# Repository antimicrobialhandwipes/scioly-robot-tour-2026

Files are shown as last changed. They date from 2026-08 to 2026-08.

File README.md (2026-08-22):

# Scioly Robot Tour 2025-2026
An autonomous robot developed for BTHS Science Olympiad during the **2025–2026** season.

The system combines odometry, distance-sensing, and careful calibration to navigate a competition course and interact with objects under strict time and dimensional constraints.
#

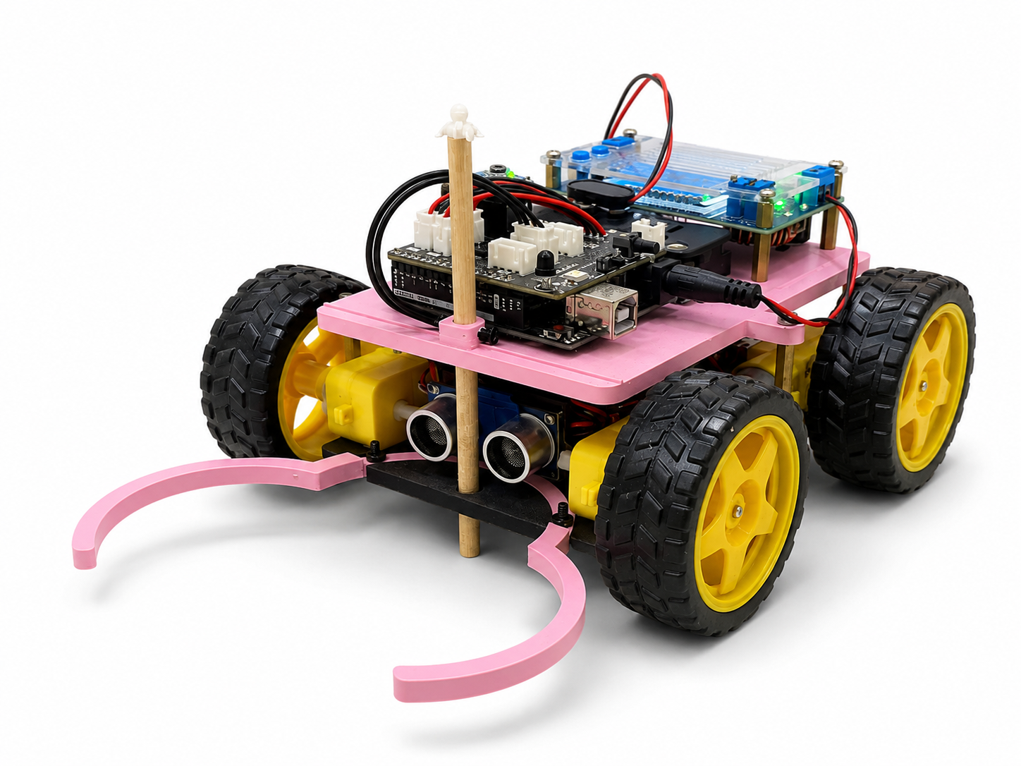
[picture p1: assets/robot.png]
Robot Tour robot


## Overview
<u>Robot Tour</u> requires an autonomous vehicle to navigate a predefined course, interact with objects, and complete a sequence of movements accurately within a specified amount of time.

I developed and iterated on the robot's mechanical and software systems throughout the 2024–2025 and 2025–2026 seasons. The 2025–2026 implementation significantly expanded on its original distance-measuring system by **adding a magnetic encoder that directly measured how far the wheels rotated**. Instead of brute-forcing distance based mainly on time, the robot could use the physical circumference of its wheels to calculate how far it had traveled.

- **MT6701 magnetic encoder** — measures wheel rotation for distance estimation
- **MPU6050 IMU** — provides yaw measurements for heading correction
- **Ultrasonic sensor** — measures distance to objects and course features
- **RGB LED** — provides real-time motion and calibration feedback

## Results

### 2025-2026
[**Science Olympiad at the University of Pennsylvania (SOUPS)**](https://www.duosmium.org/results/2026-02-14_penn_invitational_c/): 3rd Place<br>
[**Princeton University Science Olympiad**](https://www.duosmium.org/results/2026-02-07_princeton_invitational_c/): 5th Place<br>
[**New York City South Regional Tournament**](https://www.duosmium.org/results/2026-01-31_NY_nyc_south_regional_c/): 5th Place<br>
[**Rickards Science Olympiad Invitational**](https://www.duosmium.org/results/2025-11-01_rickards_invitational_c/): 9th Place<br>

### 2024-2025
[**New York Science Olympiad State Tournament**](https://www.duosmium.org/results/2025-03-21_NY_states_c/): 1st Place<br>
[**New York City South Regional Tournament**](https://www.duosmium.org/results/2025-02-01_NY_new_york_city_south_regional_c/): 1st Place<br>
[**Columbia University Science Olympiad**](https://www.duosmium.org/results/2025-01-25_columbia_university_invitational_c/): 2nd Place<br>
[**Boyceville Satellite Science Olympiad Invitational**](https://www.duosmium.org/results/2024-12-02_boyceville_satellite_invitational_c/): 3rd Place<br>
[**Rickards Science Olympiad Invitational**](https://www.duosmium.org/results/2024-11-02_rickards_invitational_c/): 5th Place<br>

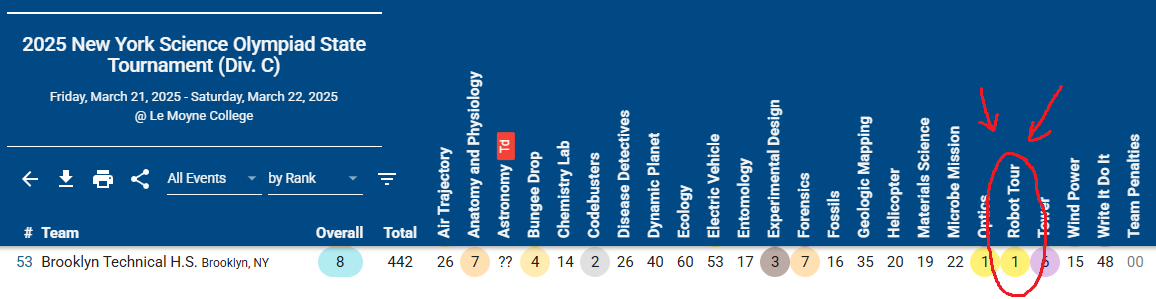
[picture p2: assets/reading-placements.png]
Reading Placements


## Motion Control
### Encoder-Based Movement
The **2024-2025** version mainly used carefully calibrated timing to control how long the motors ran to reach a certain distance. (which later caused issues with friction and voltage)

For **2025–2026**, I transitioned to an encoder-based measurement approach.

## Heading Control
The MPU6050 provides a continuous yaw feedback during movement to keep the robot straight (a basic proportional controller)

The controller compares the measured yaw against a target heading:

- **yaw error = target heading − measured heading**

If the robot begins to stray from its target heading, the motor speeds adjust asymmetrically to correct the trajectory. 

The same feedback loop is also used during turns. The robot progressively reduces its turning speed as it approaches a target heading, allowing it to settle within approximately a one-degree tolerance during calibration.

## Calibration
Because the robot is affected by real-world physical factors, I'm considering factors, such as robot dimensions, wheel diameter, motor characteristics, battery voltage, surface friction, alignment, and sensor offsets. So therefore I calibrated movement systems around the physical robot.

This repository includes a `Robot Tour Data Sheet` documenting measured movements and the corresponding movement commands that we commonly need for competitions.

The calibration data covers:
* Forward movement
* Distance-based approaches
* Distance-based corrections
* 90° turns
* 180° turns
* Positioning relative to course objects

The goal was not simply to make the robot complete one track, but to develop reusable movement primitives that could be calibrated and integrated into different tracks.

## Movement Glossary
| Function: | Purpose: |
| :---- | ----- |
| fw(d) | Move forward **d** centimeters |
| bw(d) | Move backward **d** centimeters |
| r() | Rotate 90° right |
| l() | Rotate 90° left |
| r180() | Rotate 180° right |
| l180() | Rotate 180° left |
| fu(d) | Move forward until **d** centimeters from an object |
| until(d) | Move backwards until **d** centimeters from an object |

## Example Track

The `Example Track/` directory contains a complete track that won us 3rd at the SOUPS (Science Olympiad at the University of Pennsylvania).

For example:

fu(21.5);<br>
l();<br>
fw(50);<br>
fw(50);<br>
r();<br>
fw(50);<br>
l();<br>
fw(50);<br>
l180();<br>
fw(50);<br>

The corresponding `directions.txt` file provides a human-readable representation of the route before it is inputted into the Arduino program. This separation makes it easier to design and revise routes.

## Development History
### 2024–2025

The original version relied heavily on empirically calibrated timing constants.

For example, forward and backward movement were determined using relationships between:

- movement distance
- motor speed
- elapsed time
- braking behavior

This approach was functional but sensitive to changes in battery voltage, motor behavior, and physical conditions.

### 2025–2026

The movement system was redesigned around measured wheel rotation.

Major improvements included:

- Added MT6701 magnetic encoder
- Replaced primary distance estimation with encoder-based odometry
- Added acceleration/deceleration profiles
- Improved heading correction
- Added dedicated 180° turning routines
- Refined ultrasonic distance-based positioning
- Reorganized movement into reusable high-level primitives
- Added documented physical calibration data

## Hardware

Constructed utilizing parts from a [ELEGOO Robot Car Kit](https://www.amazon.com/dp/B07KPZ8RSZ?lv=shuf&channelId=500&plpRedirect=mhFallback) (Arduino UNO, Kit Shield, MPU6050 IMU, Yellow DC gearbox motors), two custom CAD-designed baseplates and claw grips, dowel with a cadded ducky for good luck, ultrasonic sensors, 8-pack battery holder (w/ non-rechargeable alkaline batteries as per construction parameters), magnetic encoders (MT6701), and [DC Buck Converter](https://a.co/d/06xhJ2Bz),

Designed on Bambu Studio and printed on Bambu Lab A1 Mini

Constructed following the 2025-2026 SciOly build parameters: [Link](https://drive.google.com/file/d/1CcOrLIdCGCBEwNyRmbU7zTlQBbmRYcFV/view)

## Credits
The 2024–2025 implementation was based in part on a kit design and includes code credited to Jason Wei. (CWRU' 29)

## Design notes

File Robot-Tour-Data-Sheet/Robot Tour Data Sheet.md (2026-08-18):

**Robot Tour Movement Data Sheet:**

Disclaimers: 

\* These are all manual calibrations based off the robot’s physical conditions (length and width)  
\* forward(), backward(), forwardUntil(), until() are all measurements based off the dowel  
\* Movement functions have integer arguments, so decimals get truncated

| Situation: | Before: | After: | Code: |
| :---- | :---- | :---- | ----- |
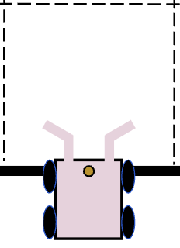
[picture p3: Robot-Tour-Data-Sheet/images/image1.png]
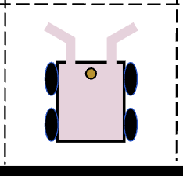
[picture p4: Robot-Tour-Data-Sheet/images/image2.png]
| **→ first move:** Positioned in the middle of the grid |  |  | forward(25); |
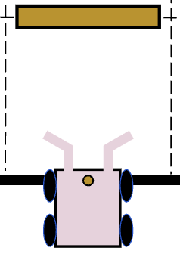
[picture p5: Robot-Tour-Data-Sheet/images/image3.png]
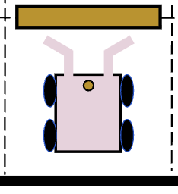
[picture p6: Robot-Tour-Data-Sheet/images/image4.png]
| **→ first move:** Positioned in the middle of the grid |  |  | forwardUntil(17); |
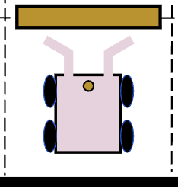
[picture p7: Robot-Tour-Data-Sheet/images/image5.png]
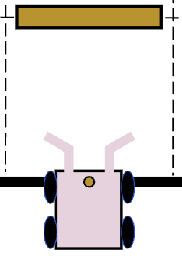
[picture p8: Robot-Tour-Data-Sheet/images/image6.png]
| Positioned in the middle of the grid |  |  | until(17); |
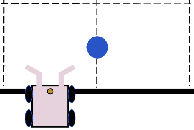
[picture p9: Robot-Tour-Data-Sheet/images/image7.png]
| Positioned to the middle of the box before turning to move a bottle |  |  | forward(25); right(); / left(); |
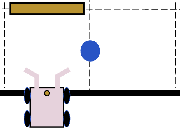
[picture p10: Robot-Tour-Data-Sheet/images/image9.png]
| Positioned to the middle of the box before turning to move a bottle |  |  | forwardUntil(17); right(); / left(); |
| Positioned to the middle of the box before turning to move a bottle |  |  | until(17); right(); / left(); |
| Use l180 to move a bottle from an inaccessible area and positioning it back to move a bottle to the center of the grid |  |  | fw(50); l180(); / r180(); fw(50); |

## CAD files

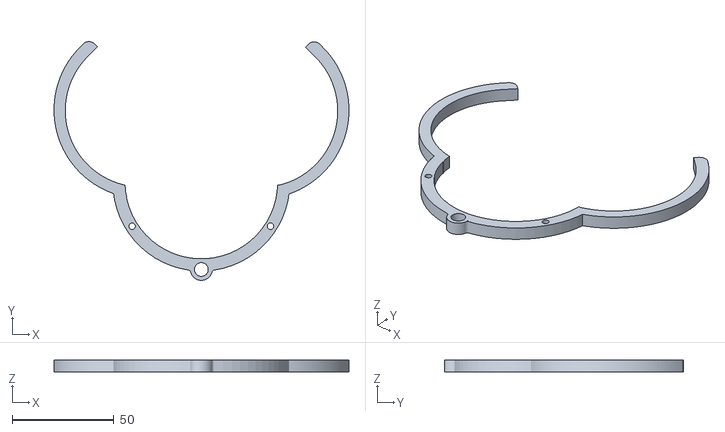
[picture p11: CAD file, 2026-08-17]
CAD/claw.stl
145.0 x 117.4 x 6.01

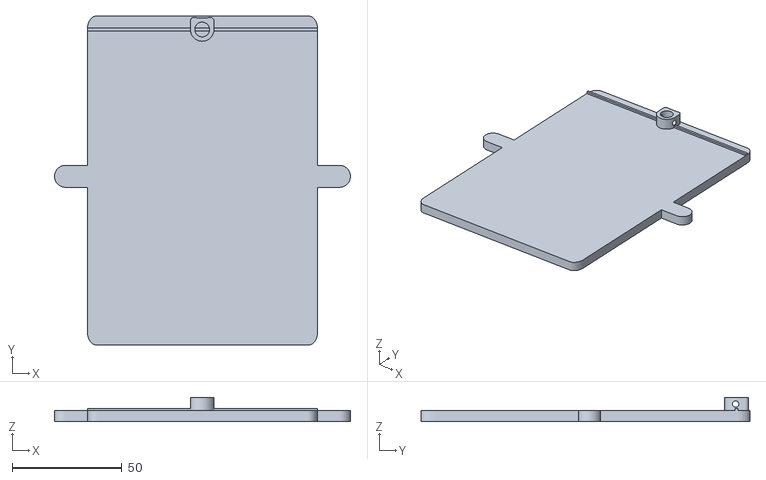
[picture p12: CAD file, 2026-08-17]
CAD/top-plate.stl
135.0 x 150.0 x 10.9

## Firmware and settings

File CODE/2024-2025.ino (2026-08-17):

//courtesy of Jason Wei (CWRU '29)

#include <Wire.h>
#include <MPU6050_light.h>
MPU6050 mpu(Wire);
#define STBY 3  //power of both motors;     high-on
#define PWMA 5  //power of right motor;     high-on
#define PWMB 6  //power of left motor;      high-on
#define AIN 7   //direction of right motor; high-forward
#define BIN 8   //direction of left motor;  high-forward
#define TRIG 13
#define ECHO 12
#define VOL_MEASURE_PIN A3

long duration;
float distance;
double yawTo = 0; // getanglez

#include "FastLED.h"
#define PIN_RBGLED 4
#define NUM_LEDS 1
CRGB leds[NUM_LEDS];
uint32_t Color(uint8_t r, uint8_t g, uint8_t b){
    return (((uint32_t)r << 16) | ((uint32_t)g << 8) | b);
}
const uint32_t RED = Color(255, 0, 0);
const uint32_t ORANGE = Color(255, 165, 0);
const uint32_t YELLOW = Color(255, 255, 0);
const uint32_t GREEN = Color(0, 255, 0);
const uint32_t BLUE = Color(0, 0, 255);

class Motor {
    int stbyPin;
    int inPin;
    int pwmPin;
public:
    Motor(int stbyPin, int inPin, int pwmPin) {
        this->stbyPin = stbyPin;
        this->inPin = inPin;
        this->pwmPin = pwmPin;
    }
    void Drive(int speed) {
        digitalWrite(inPin, speed > 0);
        speed = abs(speed);
        analogWrite(pwmPin, speed);
    }
};
Motor motor1(STBY, AIN, PWMA);  // right motor
Motor motor2(STBY, BIN, PWMB);  // left motor

void pinSetup() {
    pinMode(AIN, OUTPUT);
    pinMode(PWMA, OUTPUT);
    pinMode(BIN, OUTPUT);
    pinMode(PWMB, OUTPUT);
    pinMode(STBY, OUTPUT);
    digitalWrite(STBY, HIGH);
    pinMode(ECHO, INPUT);
    pinMode(TRIG, OUTPUT);
    pinMode(VOL_MEASURE_PIN, INPUT);
    FastLED.addLeds<NEOPIXEL, PIN_RBGLED>(leds, NUM_LEDS);
    FastLED.setBrightness(1);
    FastLED.showColor(ORANGE);
    Serial.begin(9600);
    Wire.begin();
    mpu.begin();
    delay(1000);
    mpu.calcGyroOffsets();
}

void setup() {
    pinSetup();
    check();
    Serial.println("*END*");
    FastLED.showColor(BLUE);
}

void loop() {
    Serial.println(Voltage_Measure());
    /*
    TIME LIMIT: __000 milliseconds
    numForwardBackward = ___
    numberLeftRight = ___
    totalDistance = ___
    timeForwardBackward = totalDistance*21 + brakeTime*numForwardBackward
    timeLeftRight = numberLeftRight * 445 + brakeTime*numberLeftRight
              = numberLeftRight (445 + brakeTime)
    TIME LIMIT = timeForwardBackward + timeLeftRight =
    SOLVE for brake constant
    */








    /* Time without forwardUntil:
    TimeLimit: __000 milliseconds
    FB_time = (TimeLimit - numberLeftRight * 1000) / numberForwardBackward
    */








    // time with forwardUntil: may have to subtract an additional (numberForwardUntil * 1600) from the time limit
}

const int FB_time = 1622;
const int FU_time = 1600;
const int turn_time = 1000;

void check() {
    if (FB_time > 3500 || FU_time > 2500) {
        delay(1000000000);
    }
    if (turn_time > 2000) {
        delay(1000000000);
    }
}

// MOTOR SPEED
const int SPEED = 170;
const double FB_CONSTANT = 29;

void forward(int d) {
    double timer = millis();
    while (millis() < timer + FB_time || millis() < timer + d * FB_CONSTANT) {
        mpu.update();
        double yaw = mpu.getAngleZ();
        if (millis() >= timer + d * FB_CONSTANT) {
            motor1.Drive(0);
            motor2.Drive(0);
        } else {
            if (yaw <= yawTo + 1.5 && yaw >= yawTo - 1) {
                motor1.Drive(SPEED);
                motor2.Drive(SPEED);
                FastLED.showColor(GREEN);
            } else if (yaw < yawTo - 1) {
                motor1.Drive(SPEED);
                motor2.Drive(SPEED - 30);
                FastLED.showColor(RED);
            } else if (yaw > yawTo + 1) {
                motor1.Drive(SPEED - 30);
                motor2.Drive(SPEED);
                FastLED.showColor(RED);
            }
        }
    }
    motor1.Drive(0);
    motor2.Drive(0);
}

void backward(int d) {
    double timer = millis();
    while (millis() < timer + FB_time || millis() < timer + d * FB_CONSTANT) {
        mpu.update();
        double yaw = mpu.getAngleZ();
        Serial.println(yaw);
        if (millis() >= timer + d * FB_CONSTANT) {
            motor1.Drive(0);
            motor2.Drive(0);
        } else {
            if (yaw <= yawTo + 1 && yaw >= yawTo - 1) {
                motor1.Drive(-SPEED);
                motor2.Drive(-SPEED);
                FastLED.showColor(GREEN);
            } else if (yaw < yawTo - 1) {
                motor1.Drive(-SPEED + 30);
                motor2.Drive(-SPEED);
                FastLED.showColor(RED);
            } else if (yaw > yawTo + 1) {
                motor1.Drive(-SPEED);
                motor2.Drive(-SPEED + 30);
                FastLED.showColor(RED);
            }
        }
    }
    motor1.Drive(0);
    motor2.Drive(0);
}

void right() {
    yawTo -= 90;
    calibrate();
}

void left() {
    yawTo += 90;
    calibrate();
}

void calibrate() {
    double timer = millis();
    while (millis() < timer + turn_time) {
        mpu.update();
        double yaw = mpu.getAngleZ();
        Serial.println(yaw);
        if (abs(yaw - yawTo) <= 1) {
            motor1.Drive(0);
            motor2.Drive(0);
            FastLED.showColor(GREEN);
        } else {
            int speed = 0;
            if (yaw < yawTo - 30) {
                speed = 170;
                FastLED.showColor(RED);
            } else if (yaw > yawTo + 30) {
                speed = -170;
                FastLED.showColor(RED);
            } else if (yaw < yawTo - 10) {
                speed = 140;
                FastLED.showColor(ORANGE);
            } else if (yaw > yawTo + 10) {
                speed = -140;
                FastLED.showColor(ORANGE);
            } else if (yaw < yawTo - 1) {
                speed = 50;
                FastLED.showColor(YELLOW);
            } else if (yaw > yawTo + 1) {
                speed = -50;
                FastLED.showColor(YELLOW);
            }
            motor1.Drive(speed);
            motor2.Drive(-speed);
        }
    }
    motor1.Drive(0);
    motor2.Drive(0);
}

void forwardUntil(double amount) {
    double timer = millis();
    while (millis() < timer + FU_time) { // we may have to do 1600 * the total number of forward untils
        mpu.update();
        int speed;
        double yaw = mpu.getAngleZ();
        if (get_distance() > amount + 20) {
            speed = 180;
            FastLED.showColor(RED);
        } else if (get_distance() > amount + 10) {
            speed = 150;
            FastLED.showColor(ORANGE);
        } else if (get_distance() > amount + 5) {
            speed = 80;
            FastLED.showColor(YELLOW);
        } else {
            speed = 0;
            FastLED.showColor(GREEN);
        }
       
        if (yaw <= yawTo + 1 && yaw >= yawTo - 1) {
            motor1.Drive(speed);
            motor2.Drive(speed);
        } else if (yaw < yawTo - 1) {
            motor1.Drive(speed);
            motor2.Drive(speed - 30);
        } else if (yaw > yawTo + 1) {
            motor1.Drive(speed - 30);
            motor2.Drive(speed);
        }
    }
    motor1.Drive(0);
    motor2.Drive(0);
}

void until(double amount) {
    double timer = millis();
    while (millis() < timer + 1000) {
        mpu.update();
        double yaw = mpu.getAngleZ();
        int speed = 80;
        if (get_distance() >= amount - 1 && get_distance() <= amount + 1) {
            motor1.Drive(0);
            motor2.Drive(0);
        } else if (get_distance() > amount) {
            if (yaw <= yawTo + 1 && yaw >= yawTo - 1) {
                motor1.Drive(speed);
                motor2.Drive(speed);
            } else if (yaw < yawTo - 1) {
                motor1.Drive(speed);
                motor2.Drive(speed - 30);
            } else if (yaw > yawTo + 1) {
                motor1.Drive(speed - 30);
                motor2.Drive(speed);
            }
        } else if (get_distance() < amount){
            if (yaw <= yawTo + 1 && yaw >= yawTo - 1) {
                motor1.Drive(-speed);
                motor2.Drive(-speed);
                FastLED.showColor(GREEN);
            } else if (yaw < yawTo - 1) {
                motor1.Drive(-speed + 30);
                motor2.Drive(-speed);
                FastLED.showColor(RED);
            } else if (yaw > yawTo + 1) {
                motor1.Drive(-speed);
                motor2.Drive(-speed + 30);
                FastLED.showColor(RED);
            }
        } else {
            motor1.Drive(0);
            motor2.Drive(0);
            FastLED.showColor(GREEN);
        }
    }
    motor1.Drive(0);
    motor2.Drive(0);
}

double get_distance() {
    digitalWrite(TRIG, LOW);
    delayMicroseconds(2);
    digitalWrite(TRIG, HIGH);
    delayMicroseconds(10);
    digitalWrite(TRIG, LOW);
    duration = pulseIn(ECHO, HIGH);
    distance = duration * 0.034 / 2;
    Serial.println(distance - 2);
    if (distance > 150) {
        distance = 0;
    }
    return distance - 2;
}

double Voltage_Measure() {
    double voltage = (analogRead(VOL_MEASURE_PIN) * 5 ) * ((10 + 1.5) / 1.5)/ 1024;
    return voltage + (voltage * 0.08);
}

double brake_constant(double numFB, double numLR, double target_time) {
  double constant = ((target_time * 1000) - (numFB * 50 * 21) - (numLR * 445)) / (numFB + numLR);
  return constant;
}

// ((target_time * 1000) - (numFB * 50 * 21) - (numLR * 445)) / (numFB + numLR)
// ((20000) - (10 * 50) - (10 * 445)) / (10 + 4);

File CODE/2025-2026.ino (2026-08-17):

#include <Wire.h>
#include <MPU6050_light.h>
#include "FastLED.h"
#include "MT6701.h"

// ======= PINS & SETUP ======
#define STBY 3           // power of both motors; high-on
#define PWMA 5           // power of right motor; high-on
#define PWMB 6           // power of left motor; high-on
#define AIN 7            // direction of right motor; high-forward
#define BIN 8            // direction of left motor; high-forward
#define TRIG 13          // ultrasonic trigger
#define ECHO 12          // ultrasonic echo
#define VOL_MEASURE_PIN A3
#define PIN_RBGLED 4
#define NUM_LEDS 1

// ======= GLOBALS ===========
long duration;
float distance;
double yawTo = 0;         // target yaw angle

// ======= ENCODERS ==========
MT6701 encoder;

const double WHEEL_DIAMETER_CM = 7.22;
const double WHEEL_CIRCUMFERENCE_CM = WHEEL_DIAMETER_CM * PI;
float last_angle = 0;
double total_rotations = 0;

// ======= LED COLORS ========
CRGB leds[NUM_LEDS];
uint32_t Color(uint8_t r, uint8_t g, uint8_t b) {
    return (((uint32_t)r << 16) | ((uint32_t)g << 8) | b);
}

const uint32_t RED = Color(255, 0, 0);
const uint32_t ORANGE = Color(255, 165, 0);
const uint32_t YELLOW = Color(255, 255, 0);
const uint32_t GREEN = Color(0, 255, 0);
const uint32_t BLUE = Color(0, 0, 255);

// ======= MPU6050 ===========
MPU6050 mpu(Wire);

// ======= MOTOR CLASS =======
class Motor {
int stbyPin;
int inPin;
int pwmPin;
public:
    Motor(int stbyPin, int inPin, int pwmPin) {
    this->stbyPin = stbyPin;
        this->inPin = inPin;
        this->pwmPin = pwmPin;
    }
    void Drive(int speed) {
        digitalWrite(inPin, speed > 0);
        speed = abs(speed);
        analogWrite(pwmPin, speed);
    }
};
Motor motor1(STBY, AIN, PWMA);  // right side
Motor motor2(STBY, BIN, PWMB);  // left side

// ===========================
// ======= SETUP HELPERS =====
// ===========================
void pinSetup() {
    pinMode(AIN, OUTPUT);
    pinMode(PWMA, OUTPUT);
    pinMode(BIN, OUTPUT);
    pinMode(PWMB, OUTPUT);
    pinMode(STBY, OUTPUT);
    digitalWrite(STBY, HIGH);
    pinMode(ECHO, INPUT);
    pinMode(TRIG, OUTPUT);
    pinMode(VOL_MEASURE_PIN, INPUT);
    FastLED.addLeds<NEOPIXEL, PIN_RBGLED>(leds, NUM_LEDS);
    FastLED.setBrightness(1);
    FastLED.showColor(ORANGE);
    Serial.begin(9600);
    Wire.begin();
    mpu.begin();
    delay(1000);
    mpu.calcGyroOffsets();
    encoder.initializeI2C();
    last_angle = encoder.angleRead();
}

const int target_time = 60;
// note = if the last move is a forward / backward, subtract 1 from NUM_OF_FB
const int NUM_OF_FB = 5;
const int NUM_OF_FU = 5;
const int NUM_OF_LR = 5;
const int NUM_OF_180s = 5;
const int NUM_OF_UN = 5;

void setup() {
    pinSetup();
    check();

    // directions:






    Serial.println("*END*");
    FastLED.showColor(BLUE);
}

void loop() {
    Serial.println(Voltage_Measure());
}

const int until_time = 1000; // calibrate
const int turn_time = 1000;  // calibrate
const int time_180s = 4500;  // calibrate
const int FU_time = 1600;    // calibrate
//const int FB_time = (((target_time * 1000) - ((NUM_OF_LR * turn_time) + (NUM_OF_FU * FU_time) + (NUM_OF_UN * until_time + (NUM_OF_180s * time_180s)))) / NUM_OF_FB );
const int FB_time = 1500;

const int SPEED = 204;

void check() {
    if (FB_time > 3500 || FU_time > 2500) {
        delay(1000000000);
    }
    if (turn_time > 2000) {
        delay(1000000000);
    }
}

void fw(int d) {
    double timer = millis();
    total_rotations = 0;
    last_angle = encoder.angleRead();

    double accelStart = d * 0.125;
    double decelStart = d * 0.875;
    double minSpeed = SPEED / 3.0;
    double currentDistance = 0;

    while (!(currentDistance >= d && millis() >= timer + FB_time)) {
        currentDistance = updateEncoder() * WHEEL_CIRCUMFERENCE_CM;
        if (currentDistance >= d) {
            motor1.Drive(0);
            motor2.Drive(0);
            continue;
        }

        mpu.update();
        double yaw = mpu.getAngleZ();
        double offset = 0;
        int currentSpeed = SPEED;

        if (currentDistance < accelStart) {
            double scale = currentDistance / accelStart;
            currentSpeed = minSpeed + (SPEED - minSpeed) * (1 - exp(-4 * scale));
        }
        if (currentDistance > decelStart) {
            double scale = (d - currentDistance) / (d - decelStart);
            currentSpeed = minSpeed + (SPEED - minSpeed) * exp(-4 * (1 - scale));
        }

        if (yaw <= yawTo + 1.5 && yaw >= yawTo - 1) {
            motor1.Drive(currentSpeed);
            motor2.Drive(currentSpeed + offset);
            FastLED.showColor(GREEN);
        }else if (yaw < yawTo - 1) {
            motor1.Drive(currentSpeed);
            motor2.Drive(currentSpeed - 30 + offset);
            FastLED.showColor(RED);
        }else {
            motor1.Drive(currentSpeed - 30);
            motor2.Drive(currentSpeed + offset);
            FastLED.showColor(RED);
        }
    }

    motor1.Drive(0);
    motor2.Drive(0);
}

void bw(int d) {
    double timer = millis();
    total_rotations = 0;
    last_angle = encoder.angleRead();

    double accelStart = d * 0.125;
    double decelStart = d * 0.875;
    double minSpeed = SPEED / 3.0;
    double currentDistance = 0;

    while (!(abs(currentDistance) >= d && millis() >= timer + FB_time)) {
        currentDistance = updateEncoder() * WHEEL_CIRCUMFERENCE_CM;
        if (abs(currentDistance) >= d) {
            motor1.Drive(0);
            motor2.Drive(0);
            continue;
        }

        mpu.update();
        double yaw = mpu.getAngleZ();
        double offset = 0;
        int currentSpeed = SPEED;

        if (abs(currentDistance) < accelStart) {
            double scale = abs(currentDistance) / accelStart;
            currentSpeed = minSpeed + (SPEED - minSpeed) * (1 - exp(-4 * scale));
        }
        if (abs(currentDistance) > decelStart) {
            double scale = (d - abs(currentDistance)) / (d - decelStart);
            currentSpeed = minSpeed + (SPEED - minSpeed) * exp(-4 * (1 - scale));
        }

        if (yaw <= yawTo + 1.5 && yaw >= yawTo - 1) {
            motor1.Drive(-currentSpeed);
            motor2.Drive(-currentSpeed - offset);
            FastLED.showColor(GREEN);
        }else if (yaw < yawTo - 1) {
            motor1.Drive(-currentSpeed + 30);
            motor2.Drive(-currentSpeed - offset);
            FastLED.showColor(RED);
        }else {
            motor1.Drive(-currentSpeed);
            motor2.Drive(-currentSpeed + 30 - offset);
            FastLED.showColor(RED);
        }
    }
    motor1.Drive(0);
    motor2.Drive(0);
}

double updateEncoder() {
    float current_angle = encoder.angleRead();
    float delta = current_angle - last_angle;
    if (delta > 180.0) delta -= 360.0;
    else if (delta < -180.0) delta += 360.0;
    total_rotations += delta / 360.0;
    last_angle = current_angle;
    return total_rotations;
}

void r() {
    yawTo -= 90;
    calibrate();
}
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

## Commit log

2026-08-17 added code from active scioly seasons and CAD files
    [claw.stl, top-plate.stl]
2026-08-17 Included Example Track and a movement sheet
